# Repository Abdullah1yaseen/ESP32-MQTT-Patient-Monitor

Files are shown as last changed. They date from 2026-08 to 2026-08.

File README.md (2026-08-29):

# ESP32-MQTT-Patient-Monitor

Offline IoT patient monitoring system built on two ESP32 units communicating over a local WiFi network via MQTT — no internet or external router required. A sender unit reads vital signs from the patient, and a receiver unit hosts the network, broker, and display. 🩺📡

## Requirements

**Hardware:**

* 2x ESP32 Dev Board (one sender, one receiver)
* MAX30102 Pulse Oximeter Sensor (heart rate + SpO2)
* MLX90614 Infrared Temperature Sensor (body + ambient temp)
* SH1106 OLED Display (I2C) — sender status screen
* ILI9341 TFT Display (SPI) — receiver monitor screen
* 5x 3.7V Lithium-ion batteries + power switch + boost converter (step-up)

**Software:**

* Arduino IDE

**Arduino Libraries:**

* WiFi.h (built-in)
* Wire.h (built-in)
* SPI.h (built-in)
* PubSubClient
* PicoMQTT
* ArduinoJson
* Adafruit GFX Library
* Adafruit SH110X
* Adafruit MLX90614 Library
* SparkFun MAX3010x Pulse and Proximity Sensor Library (MAX30105.h)
* Ucglib
* [spo2_algorithm.h](https://github.com/Abdullah1yaseen/ESP32-MQTT-Patient-Monitor/blob/main/heartRateProject/spo2_algorithm.h) — not available via Library Manager, must be downloaded manually and placed inside the `heartRateProject` folder

## Installation

1. Clone the project

   ```
   git clone https://github.com/Abdullah1yaseen/ESP32-MQTT-Patient-Monitor.git
   ```
2. Download `spo2_algorithm.h` from the link above and place it inside the `heartRateProject` folder
3. Install all required Arduino libraries listed above
4. Upload `heartRateProjectRec` to the receiver ESP32 first (creates the WiFi AP + MQTT broker)
5. Upload `heartRateProject` to the sender ESP32 (connects to the receiver and streams sensor data)
6. Power both units and place a finger on the MAX30102 sensor to start a reading

## Project Structure

```
ESP32-MQTT-Patient-Monitor/
├── heartRateProject/                          # Sender firmware (patient side)
│   ├── heartRateProject.ino
│   └── spo2_algorithm.h      # downloaded manually, see Installation
├── heartRateProjectRec/
│   └── heartRateProjectRec/                   # Receiver firmware (monitor side)
│       └── heartRateProjectRec.ino
├── 3dDesign/                                  # 3D-printable enclosure design files
└── README.md
```

## Wiring

**Sender unit:**
| Component | ESP32 Pin |
|---|---|
| MAX30102 (SDA/SCL) | GPIO 21 / GPIO 22 |
| MLX90614 (SDA/SCL) | Shared I2C bus |
| SH1106 OLED (SDA/SCL) | Shared I2C bus |
| Battery pack | 5V via boost converter |

**Receiver unit:**
| Component | ESP32 Pin |
|---|---|
| ILI9341 TFT — DC | GPIO 2 |
| ILI9341 TFT — CS | GPIO 15 |
| ILI9341 TFT — RST | GPIO 4 |

## How It Works

1. The sender unit continuously checks the MAX30102 sensor for a finger placement using an IR threshold.
2. Once detected, it takes several consecutive readings, discards out-of-range values, and averages the rest for a more stable heart rate and SpO2 result.
3. Body and ambient temperature are read from the MLX90614 sensor and combined with the heart rate/SpO2 readings into a single JSON payload.
4. The sender connects to the receiver's local WiFi access point and publishes the JSON payload to the `patientData` MQTT topic.
5. The receiver — which runs its own WiFi AP and local MQTT broker (no internet needed) — receives the data and displays it on the TFT screen.
6. The receiver checks each value against safe thresholds:
   * SpO2 below 92% → `LOW SPO2!` alert
   * Heart rate above 120 or below 50 BPM → `ABNORMAL HR!` alert
   * Temperature outside 35–38°C → `HIGH TEMP!` alert
7. If no data is received for 30 seconds, the receiver switches to a standby screen with an animated heart icon and a simulated ECG waveform.
8. After each reading, the sender counts down 30 seconds before the next measurement; this timer can be reset remotely via a `RESET_TIMER` command on the `esp32/unit01/cmd` topic.

## Power Supply

The system runs fully off-grid using a **5x 3.7V lithium-ion battery pack**, a **power switch**, and a **boost converter (step-up)** to regulate the voltage output to a stable level for the ESP32 boards and sensors.

## Notes

* Fully offline system — no internet connection or external router is used; all communication happens over the local WiFi network created by the receiver.
* The `3dDesign` folder contains the 3D-printable enclosure files for both units.
* This project is a prototype for educational purposes and is not a certified medical device.

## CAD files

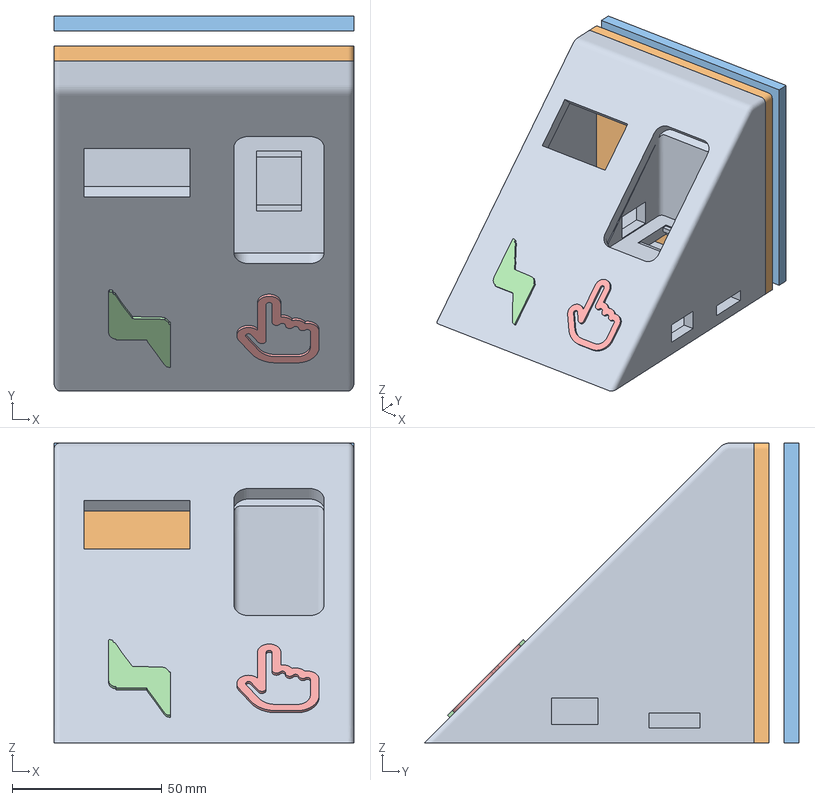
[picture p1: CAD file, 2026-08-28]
3dDesign/medicalDeviceSender.3mf
100.0 x 125.0 x 100.0 mm

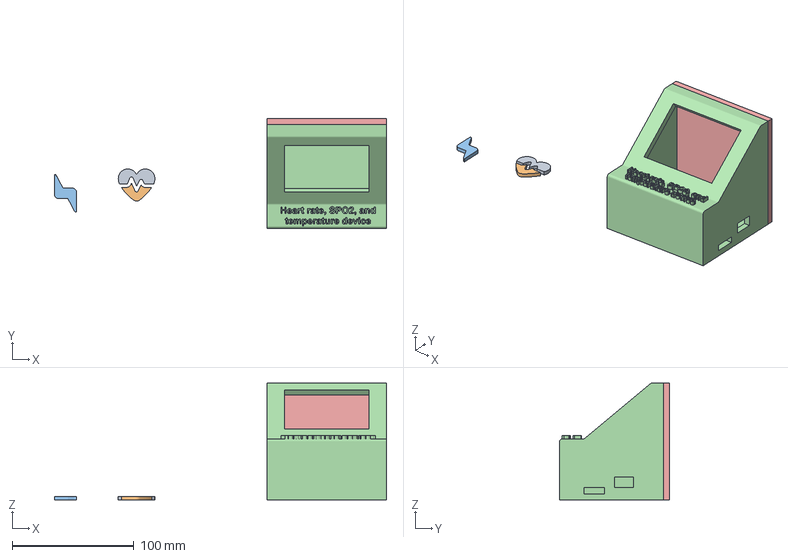
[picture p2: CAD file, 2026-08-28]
3dDesign/medicalDeviceRec.3mf
272.2 x 90.0 x 95.8 mm

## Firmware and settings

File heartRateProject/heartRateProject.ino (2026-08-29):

/*
 * ============================================================
 * Project      : ESP32 Patient Monitor
 * Author       : Abdullah Abu Halawa
 * Date         : 3-08-2026
 * Version      : 1.0
 * Device       : ESP32 Sender / MQTT Client (Publisher)
 * ============================================================
 *
 * Description:
 * ESP32-based patient monitoring system that collects
 * patient health data and transmits it in real time
 * using MQTT over a local WiFi network.
 *
 * The ESP32 connects to the receiver's local WiFi network
 * and publishes patient data as an MQTT client.
 *
 * Features:
 * - Patient health data collection
 * - MQTT communication (Publisher)
 * - Local WiFi network
 * - Real-time data transmission
 * - JSON formatted patient data
 *
 * ============================================================
 */
#include <Wire.h>
#include "MAX30105.h"
#include "spo2_algorithm.h"

#include <SPI.h>
#include <Adafruit_GFX.h>
#include <Adafruit_SH110X.h>
#include <Adafruit_MLX90614.h>

#include <WiFi.h>
#include <WiFiClient.h>
#include <PubSubClient.h>

// ============================================================
// Display
// ============================================================

#define SCREEN_WIDTH 128
#define SCREEN_HEIGHT 64

// ============================================================
// MAX30102 Settings & Constants
// ============================================================

#define bufferSize 100
#define FINGER_THRESHOLD 50000

#define MIN_NATURAL_HR 60
#define MAX_NATURAL_HR 100

#define NUM_SAMPLES_TO_AVERAGE 3

// ============================================================
// WiFi (Local Access Point Connection)
// ============================================================

const char* ssid = "ESP32_Medical_Net";
const char* password = "123456789";

// ============================================================
// MQTT - Local Server (ESP32 Receiver IP)
// ============================================================

const char* mqttServer = "192.168.4.1";
const int mqttPort = 1883;

const char* device_id = "ESP32_Pro_Unit_01";

const char* topic_telemetry = "patientData";
const char* topic_command = "esp32/unit01/cmd";
const char* topic_status = "esp32/unit01/status";

// ============================================================
// MAX30102 buffers
// ============================================================

uint32_t irBuffer[bufferSize];
uint32_t redBuffer[bufferSize];

int32_t spo2;
int32_t heartRate;

int8_t validspo2;
int8_t validHeartRate;

// ============================================================
// MQTT reset command
// ============================================================

volatile bool resetTimerTriggered = false;

// ============================================================
// Objects
// ============================================================

WiFiClient espClient;
PubSubClient client(espClient);

MAX30105 particleSensor;

Adafruit_SH1106G display(SCREEN_WIDTH, SCREEN_HEIGHT, &Wire, -1);
Adafruit_MLX90614 tempSensor = Adafruit_MLX90614();

// ============================================================
// Data structure
// ============================================================

typedef struct structMsg {
    int32_t spo2;
    int32_t heartRate;
    int8_t validspo2;
    int8_t validHeartRate;
    float objectTemp;
    float ambientTemp;
} structMsg;

structMsg collectedData;

// ============================================================
// Display function
// ============================================================

void displayMessage(const char* line1, const char* line2 = "") {
    display.clearDisplay();
    display.setTextSize(1);
    display.setTextColor(SH110X_WHITE);

    display.setCursor(0, 20);
    display.println(line1);

    if (strlen(line2) > 0) {
        display.setCursor(0, 35);
        display.println(line2);
    }

    display.display();
}

// ============================================================
// MQTT callback
// ============================================================

void mqttCallback(char* topic, byte* payload, unsigned int length) {
    String msg = "";
    for (unsigned int i = 0; i < length; i++) {
        msg += (char)payload[i];
    }

    Serial.println();
    Serial.println("========== MQTT MESSAGE ==========");
    Serial.print("Topic: ");
    Serial.println(topic);
    Serial.print("Message: ");
    Serial.println(msg);
    Serial.println("==================================");

    if (String(topic) == topic_command && msg == "RESET_TIMER") {
        Serial.println("[MQTT] RESET_TIMER command received!");
        resetTimerTriggered = true;
    }
}

// ============================================================
// WiFi setup
// ============================================================

void wifiSetup() {
    Serial.println();
    Serial.println("==================================");
    Serial.println("           WIFI SETUP");
    Serial.println("==================================");
    Serial.print("Connecting to AP: ");
    Serial.println(ssid);

    WiFi.mode(WIFI_STA);
    WiFi.begin(ssid, password);

    int attempts = 0;
    while (WiFi.status() != WL_CONNECTED) {
        delay(500);
        Serial.print(".");
        attempts++;

        if (attempts >= 60) {
            Serial.println("\n[WiFi] Connection failed!");
            return;
        }
    }

    Serial.println("\n[WiFi] Connected!");
    Serial.print("[WiFi] IP Address: ");
    Serial.println(WiFi.localIP());
}

// ============================================================
// MQTT connection
// ============================================================

void mqttConnect() {
    while (!client.connected()) {
        Serial.print("[MQTT] Connecting to Local Receiver Broker...");
        if (client.connect(device_id, topic_status, 1, true, "Offline")) {
            Serial.println(" Connected!");
            client.publish(topic_status, "Online", true);
            client.subscribe(topic_command);
        } else {
            Serial.print(" Failed, rc=");
            Serial.println(client.state());
            delay(5000);
        }
    }
}

// ============================================================
// I2C Scanner
// ============================================================

void scanI2C() {
    byte error;
    int devices = 0;
    for (byte address = 1; address < 127; address++) {
        Wire.beginTransmission(address);
        error = Wire.endTransmission();
        if (error == 0) {
            Serial.print("[I2C] Device found at 0x");
            if (address < 16) Serial.print("0");
            Serial.println(address, HEX);
            devices++;
        }
    }
}

// ============================================================
// Setup
// ============================================================

void setup() {
    Serial.begin(115200);
    delay(1000);

    Wire.begin(21, 22);
    scanI2C();

    wifiSetup();

    client.setServer(mqttServer, mqttPort);
    client.setCallback(mqttCallback);

    if (!tempSensor.begin()) {
        Serial.println("[MLX90614] ERROR: Sensor NOT found!");
    }

    if (!display.begin(0x3C, true)) {
        while (1) delay(1000);
    }

    displayMessage("Initializing...", "Please wait");
    delay(1000);

    if (!particleSensor.begin(Wire, I2C_SPEED_FAST)) {
        displayMessage("MAX30102 Error!", "Check wiring");
        while (1) delay(1000);
    }

    particleSensor.setup(0x1F, 4, 2, 400, 411, 4096); 
    particleSensor.setPulseAmplitudeRed(0x1F);
    particleSensor.setPulseAmplitudeIR(0x1F);

    displayMessage("Ready!", "Place your finger");
}

// ============================================================
// Loop
// ============================================================

void loop() {
    if (WiFi.status() != WL_CONNECTED) wifiSetup();
    if (!client.connected()) mqttConnect();
    client.loop();

    while (!particleSensor.available()) {
        particleSensor.check();
        client.loop();
    }

    uint32_t irValue = particleSensor.getIR();
    particleSensor.nextSample();

    if (irValue < FINGER_THRESHOLD) {
        displayMessage("Place your finger");
        delay(200);
        return;
    }

    displayMessage("Finger detected", "Measuring...");
    delay(500);

 
    int32_t totalHR = 0;
    int32_t totalSpO2 = 0;
    int validReadingsCount = 0;

    for (int run = 0; run < NUM_SAMPLES_TO_AVERAGE; run++) {
        displayMessage("Scanning...", "Hold Still");

        for (int i = 0; i < bufferSize; i++) {
            while (!particleSensor.available()) {
                particleSensor.check();
                client.loop();
            }
            redBuffer[i] = particleSensor.getRed();
            irBuffer[i] = particleSensor.getIR();
            particleSensor.nextSample();
        }

        maxim_heart_rate_and_oxygen_saturation(
            irBuffer, bufferSize, redBuffer,
            &spo2, &validspo2, &heartRate, &validHeartRate
        );

        if (validHeartRate && validspo2 && heartRate >= MIN_NATURAL_HR && heartRate <= MAX_NATURAL_HR) {
            totalHR += heartRate;
            totalSpO2 += spo2;
            validReadingsCount++;
        }
    }

 
    if (validReadingsCount == 0) {
        Serial.println("[MAX30102] ERROR: Invalid or out-of-range readings!");
        
        displayMessage("Incorrect Reading", "Retrying test...");
        delay(2500);
        return;
    }

    int32_t avgHeartRate = totalHR / validReadingsCount;
    int32_t avgSpO2 = totalSpO2 / validReadingsCount;

    float objectTemp = tempSensor.readObjectTempC();
    float ambientTemp = tempSensor.readAmbientTempC();

    collectedData.heartRate = avgHeartRate;
    collectedData.spo2 = avgSpO2;
    collectedData.objectTemp = objectTemp;
    collectedData.ambientTemp = ambientTemp;
    collectedData.validHeartRate = 1;
    collectedData.validspo2 = 1;

   

    String payload = "{";
    payload += "\"heartRate\":" + String(collectedData.heartRate) + ",";
    payload += "\"spo2\":" + String(collectedData.spo2) + ",";
    payload += "\"temp\":" + String(collectedData.objectTemp, 2) + ",";
    payload += "\"ambientTemp\":" + String(collectedData.ambientTemp, 2);
    payload += "}";

    if (client.publish(topic_telemetry, payload.c_str())) {
        displayMessage("Data Sent!", "MQTT OK");
    } else {
        displayMessage("Publish Failed!", "Check MQTT");
    }

    delay(2000);

   

    resetTimerTriggered = false;

    for (int secondsLeft = 30; secondsLeft > 0; secondsLeft--) {
        if (WiFi.status() != WL_CONNECTED) wifiSetup();
        if (!client.connected()) mqttConnect();
        client.loop();

        if (resetTimerTriggered) {
            resetTimerTriggered = false;
            break;
        }

        char timeStr[10];
        sprintf(timeStr, "%02d:%02d", secondsLeft / 60, secondsLeft % 60);
        displayMessage("Next test in:", timeStr);

        delay(1000);
    }

    displayMessage("Place your finger");
    delay(500);
}

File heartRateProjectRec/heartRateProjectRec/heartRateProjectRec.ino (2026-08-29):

/*
 * ============================================================
 * Project      : ESP32 Patient Monitor
 * Author       : Abdullah Abu Halawa
 * Date         : 4-08-2026
 * Version      : 1.0
 * Device       : ESP32 Receiver / WiFi Access Point + MQTT Broker
 * ============================================================
 *
 * Description:
 * ESP32-based patient monitoring receiver that hosts a local
 * WiFi network and MQTT broker, receives real-time patient
 * health data over MQTT, and displays it on a TFT screen.
 *
 * The receiver subscribes to the patientData MQTT topic
 * and displays heart rate, SpO2, and temperature readings.
 *
 * Features:
 * - WiFi Access Point
 * - MQTT Broker
 * - Real-time patient data reception
 * - TFT display
 * - Heart rate display
 * - SpO2 display
 * - Temperature display
 * - Patient health alerts
 * - 30-second standby mode
 * - Animated blue ECG waveform
 *
 * ============================================================
 */


#include <WiFi.h>
#include <PicoMQTT.h>
#include <ArduinoJson.h>
#include "Ucglib.h"

// ============================================================
// TFT DISPLAY
// ============================================================
#define TFT_DC   2
#define TFT_CS   15
#define TFT_RST  4

Ucglib_ILI9341_18x240x320_HWSPI ucg(TFT_DC, TFT_CS, TFT_RST);

// ============================================================
// LOCAL WIFI AP CONFIGURATION
// ============================================================
const char* ap_ssid = "ESP32_Medical_Net";
const char* ap_pass = "123456789";

// ============================================================
// LOCAL MQTT BROKER
// ============================================================
PicoMQTT::Server broker;
const char* topic_telemetry = "patientData";

// ============================================================
// STANDBY SYSTEM & ECG
// ============================================================
const unsigned long STANDBY_TIMEOUT = 30000;
unsigned long lastDataTime = 0;
bool standbyMode = false;

unsigned long lastECGUpdate = 0;
const int ECG_LEFT = 20;
const int ECG_RIGHT = 300;
const int ECG_CENTER_Y = 120;
const int ECG_TOP = 80;
const int ECG_BOTTOM = 160;

int currentX = ECG_LEFT;
int prevY = ECG_CENTER_Y;

// ============================================================
// HELPER FUNCTIONS & DRAWING
// ============================================================
void drawHeart(int x, int y) {
  ucg.setColor(255, 0, 0);
  ucg.drawDisc(x - 5, y - 3, 5, UCG_DRAW_ALL);
  ucg.drawDisc(x + 5, y - 3, 5, UCG_DRAW_ALL);
  ucg.drawTriangle(x - 10, y - 2, x + 10, y - 2, x, y + 10);
}

void drawUIBase() {
  ucg.clearScreen();
  ucg.setFont(ucg_font_ncenR14_tr);
  ucg.setColor(255, 255, 255);
  ucg.setPrintPos(20, 30);
  ucg.print("Patient Monitor");

  ucg.setColor(100, 100, 100);
  ucg.drawLine(10, 40, 310, 40);

  ucg.setFont(ucg_font_6x12_tr);
  ucg.setColor(0, 255, 0);
  ucg.setPrintPos(15, 75);
  ucg.print("Heart Rate (BPM):");

  ucg.setColor(0, 255, 255);
  ucg.setPrintPos(15, 135);
  ucg.print("Oxygen SpO2 (%):");

  ucg.setColor(255, 255, 0);
  ucg.setPrintPos(15, 195);
  ucg.print("Temperature (C):");
}

void drawStandbyBase() {
  ucg.clearScreen();
  ucg.setFont(ucg_font_ncenR14_tr);
  ucg.setColor(255, 255, 255);
  ucg.setPrintPos(90, 30);
  ucg.print("Patient Monitor");

  drawHeart(160, 50);

  ucg.setColor(80, 80, 80);
  ucg.drawLine(10, 68, 310, 68);
  ucg.drawLine(10, 172, 310, 172);

  ucg.setFont(ucg_font_6x12_tr);
  ucg.setColor(255, 255, 255);
  ucg.setPrintPos(95, 195);
  ucg.print("WAITING FOR PATIENT DATA");

  ucg.setColor(120, 120, 120);
  ucg.setPrintPos(125, 215);
  ucg.print("Monitoring...");
}

int getECGY(int x) {
  int phase = (x - ECG_LEFT) % 100;
  if (phase > 20 && phase <= 25) return ECG_CENTER_Y - 5;
  else if (phase > 32 && phase <= 35) return ECG_CENTER_Y + 4;
  else if (phase > 35 && phase <= 42) return ECG_CENTER_Y - 35;
  else if (phase > 42 && phase <= 48) return ECG_CENTER_Y + 20;
  else if (phase > 55 && phase <= 68) return ECG_CENTER_Y - 10;
  return ECG_CENTER_Y;
}

void updateECG() {
  if (millis() - lastECGUpdate < 15) return;
  lastECGUpdate = millis();

  int nextX = currentX + 2;
  if (nextX > ECG_RIGHT) {
    nextX = ECG_LEFT;
    currentX = ECG_LEFT;
    prevY = ECG_CENTER_Y;
  }

  ucg.setColor(0, 0, 0);
  ucg.drawBox(nextX, ECG_TOP, 12, ECG_BOTTOM - ECG_TOP);

  int nextY = getECGY(nextX);
  ucg.setColor(255, 0, 0);
  ucg.drawLine(currentX, prevY, nextX, nextY);

  currentX = nextX;
  prevY = nextY;
}

// ============================================================
// DATA PROCESSING
// ============================================================
void processData(const String& payload) {
  lastDataTime = millis();

  if (standbyMode) {
    standbyMode = false;
    drawUIBase();
  }

  StaticJsonDocument<200> doc;
  DeserializationError error = deserializeJson(doc, payload);

  if (error) {
    Serial.print("JSON Parsing failed: ");
    Serial.println(error.f_str());
    return;
  }

  int heartRate = doc["heartRate"];
  int spo2 = doc["spo2"];
  float temp = doc["temp"];

  ucg.setColor(0, 0, 0);
  ucg.drawBox(15, 80, 200, 30);
  ucg.drawBox(15, 140, 200, 30);
  ucg.drawBox(15, 200, 200, 30);
  ucg.drawBox(10, 250, 220, 50);

  ucg.setFont(ucg_font_ncenR18_tr);

  ucg.setColor(0, 255, 0);
  ucg.setPrintPos(25, 105);
  ucg.print(heartRate);

  ucg.setColor(0, 255, 255);
  ucg.setPrintPos(25, 165);
  ucg.print(spo2);

  ucg.setColor(255, 255, 0);
  ucg.setPrintPos(25, 225);
  ucg.print(temp, 1);

  bool isDanger = false;
  String alertText = "";

  if (spo2 < 92 && spo2 > 0) {
    isDanger = true;
    alertText = "LOW SPO2!";
  } else if ((heartRate > 120 || heartRate < 50) && heartRate > 0) {
    isDanger = true;
    alertText = "ABNORMAL HR!";
  } else if (temp > 38.0 || temp < 35.0) {
    isDanger = true;
    alertText = "HIGH TEMP!";
  }

  if (isDanger) {
    ucg.setColor(255, 0, 0);
    ucg.drawBox(10, 250, 220, 45);
    ucg.setFont(ucg_font_ncenR12_tr);
    ucg.setColor(255, 255, 255);
    ucg.setPrintPos(20, 280);
    ucg.print("ALERT: ");
    ucg.print(alertText);
  } else {
    ucg.setColor(0, 150, 0);
    ucg.drawFrame(10, 250, 220, 45);
    ucg.setFont(ucg_font_6x12_tr);
    ucg.setColor(0, 255, 0);
    ucg.setPrintPos(30, 277);
    ucg.print("Status: Normal");
  }
}
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
